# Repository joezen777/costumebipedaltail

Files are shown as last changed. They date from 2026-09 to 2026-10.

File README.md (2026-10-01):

# Passive suitmation tail: Barney-style, lumbar-belt mounted, ready to print

A completely passive (no motors, electronics or pneumatics) creature-suit tail for a **5 ft 8 in (1.727 m)**
performer. The client revision asked for:
- **half the length** of the earlier tail;
- a **Barney-like reverse-sigmoid curve**: starts up, goes down, then flattens so the end sticks straight back;
- a mount on a **pharmacy lower-lumbar support belt**;
- the **mechanics approved in the Gojira variant** kept.

It was validated in a MuJoCo physics model, then built as parametric OpenSCAD and FreeCAD models. The print-ready
parts are for an Ender 3 V2 / Sprite Pro with a **1.2 mm nozzle** (no part larger than a 20 cm cube), plus a
**1:8 snap-together resin kit** for the Photon Mono 5s, and a **1:8 low-poly figurine with a protogen head** whose
back slot takes the kit's plate at 14 heights.

- Design document: [docs/barney.md](docs/barney.md)
- Documentation index: [docs/README.md](docs/README.md)
- Original brief: [docs/brief.md](docs/brief.md)

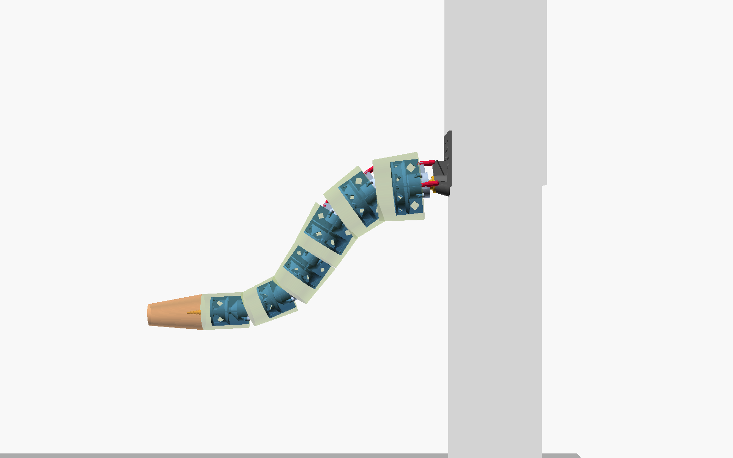
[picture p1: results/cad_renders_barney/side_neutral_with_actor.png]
Barney tail CAD assembly on the performer


---

## 1. The design

- **Length:** 0.90 m, a 6-joint × 125 mm ball-and-socket chain plus a 0.15 m rounded foam tip.
- **Proportions:** 190 mm thick at the root, 100 mm at vertebra 6, 60 mm at the tip.
- **Rest shape:** a reverse sigmoid, printed into wedge flanges on the balls. It leaves the back nearly level (6°),
  dips at up to 58° mid-tail, then the last vertebra and foam tip run level, sticking straight back.
- **Mount:** a plate strapped to the lumbar belt's back panel, with the tail root hanging 70 mm below it. One part
  covers both "attach directly" and "hang down".
- **Mechanics** (as approved):
  - dorsal + left + right extension springs per joint, anchored on cap ears (twist-stable);
  - felt seat liners;
  - a light central cord;
  - a roll-key screw per joint.

Simulated, with the masses measured from the exported parts:

| Test (as built) | Result |
|---|---|
| Rest (standing) | tail ends pointing back, skin **52 cm** above the floor |
| 30° hip snap | lag 34°, overshoot 10°, 1 swing-back, settles in 1.2 s |
| Jerk left (30° in 0.25 s) | lag 40°, overshoot 8° |
| 45° dramatic turn | overshoot 31° |
| Walking 1.5 / 2.0 steps/s | tip/hip 1.94 / 1.77 |
| Crouch (−150 mm, 10°) | min clearance 47 cm |
| Side step 300 mm | min clearance 50 cm |
| Bending over 45° | tail lifts; hip moment 7.0 N·m |
| Jump (25 cm) | no floor contact; hip moment 13.3 N·m |
| Peak moment on the lumbar belt (any test) | 13 N·m |

Levelling the end out (reverse sigmoid) also calmed the tail: walking sway dropped from ~2.4× to ~1.9× the hip,
and the snap overshoot from 17° to 10°. The end rides about half a metre off the floor.

Four changes made the short tail work, all found in simulation ([docs/barney.md](docs/barney.md)):
- **Reverse-sigmoid rest curve:** the first S-curve ended ~35° nose-down, like a hill, because it only flattened
  inside the foam tip, which can't bend. Now the last vertebra and tip are level and stick straight back.
- **Softer centring springs:** the tail first overshot the hips by 31°.
- **Round cap stop openings:** jump landings were hammering the pitch stops (23 → 7 N·m).
- **Bigger minimum ball (22 mm):** brings every neck to SF ≥ 3.5.

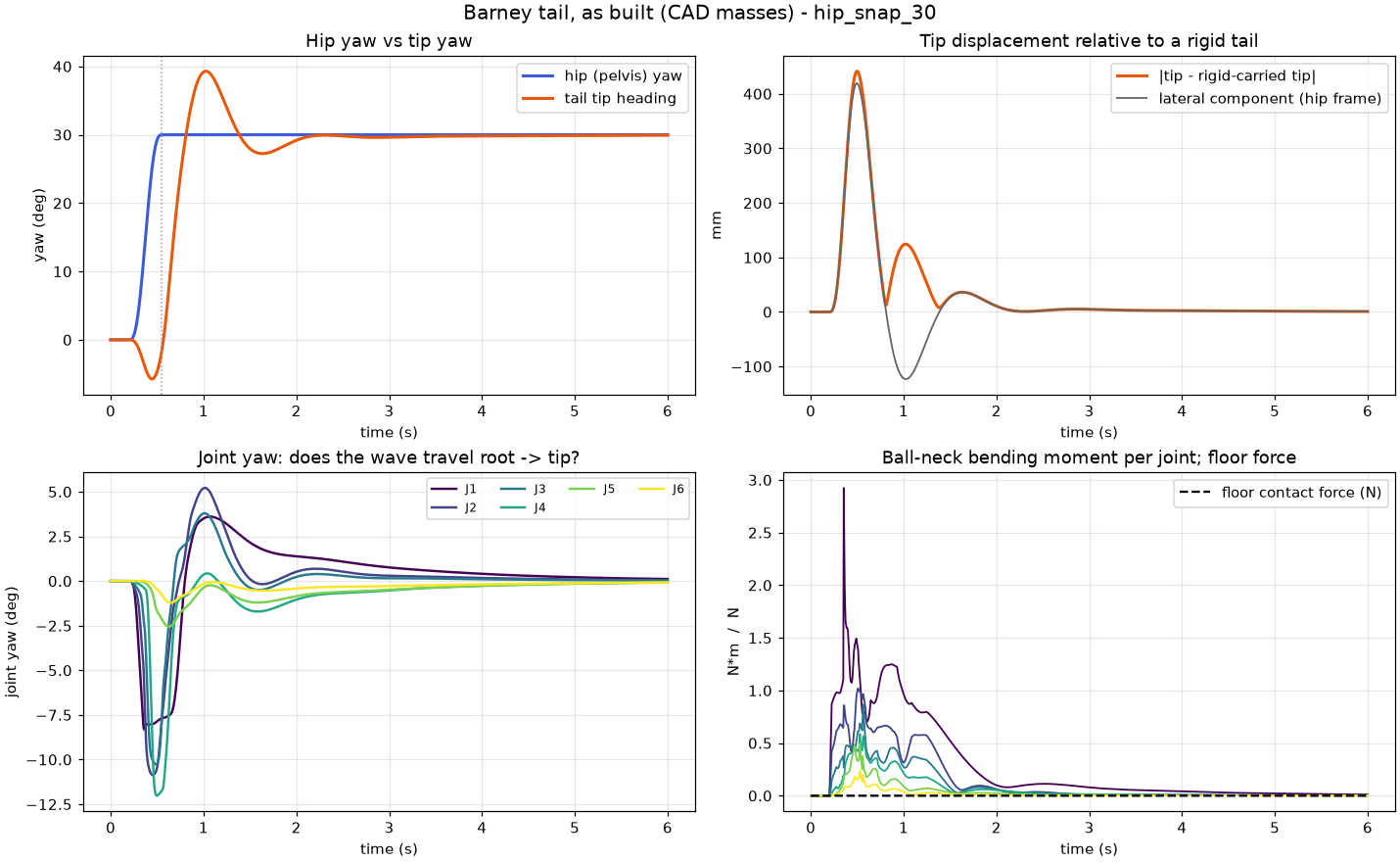
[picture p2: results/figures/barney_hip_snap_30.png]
Hip snap response


## 2. What to print (full size)

**[`cad/stl/barney/`](cad/stl/barney/): 32 print-ready STLs, 1.91 kg of PETG.**
- One hip mount, 6 vertebra bodies, 6 caps **printed as two halves each** (`cap_N_a` + `cap_N_b`), 12 ball halves
  (with the rest-curve wedges; keep them in joint order) and the tip adapter.
- **Caps are split on purpose.** A one-piece cap can't be fitted: its opening is smaller than both the ball and the
  ball's bolt flange. The two halves close around the neck of the assembled ball instead.
- Sizes and masses: [docs/tables/barney_parts.md](docs/tables/barney_parts.md).
- Settings: [docs/printing.md](docs/printing.md). PETG, 1.3 mm lines, 0.6 mm layers (0.4 mm for ball halves),
  100 % infill for ball halves 1–3.
- **No slicer supports:** the vertebra bodies and hip mount carry their own overhangs with thin structural walls
  (a 45° cone, an arched skirt, arm webs). Every part prints from `cad/stl/barney/` with slicer
  supports off; the few remaining roofs are short bridges. See [docs/printing.md](docs/printing.md).
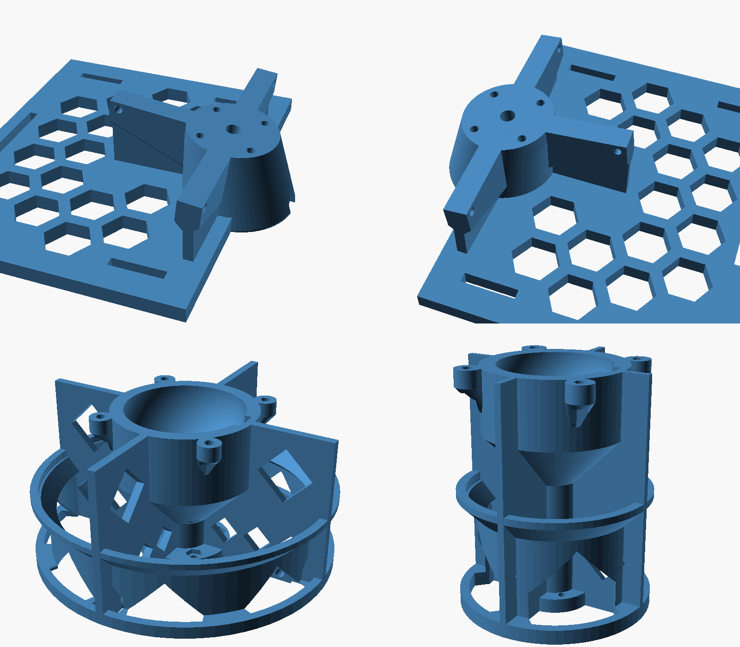
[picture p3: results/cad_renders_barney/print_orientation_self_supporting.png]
self-supporting parts
  
- The whole tail is only 6 joints, so it doubles as the prototype for the calibration tests in
  [docs/test_plan.md](docs/test_plan.md).

CAD: [`cad/openscad/suit_tail_barney.scad`](cad/openscad/suit_tail_barney.scad) (a generated variant of the
parametric [`suit_tail.scad`](cad/openscad/suit_tail.scad)); FreeCAD/STEP in [`cad/freecad/output/`](cad/freecad/output/).

### Shopping list (full-size tail)

Rough commodity prices in USD; buy about 10 % spare small hardware.

| Item | Qty | Use | ~Cost |
|---|---|---|---|
| PETG filament 1.75 mm | 3 × 1 kg | 1.91 kg of parts + purge and reprints (2 kg leaves under 0.1 kg spare) | $60 |
| 1.2 mm nozzle for the Sprite Pro | 1 | | $10 |
| M4 × 16 socket-head cap screws | 48 | 4 per cap + 4 per ball flange, 6 joints | $6 |
| M4 nylock nuts | 48 | press into the printed hex pockets | $4 |
| M4 × 12 socket-head (roll keys, all 6 joints) / M3 × 8 (tip adapter) | 6 / 4 | roll-key pins, tip adapter | $2 |
| **Extension springs** | **18** | 3 per joint; schedule in [docs/tables/barney_springs.md](docs/tables/barney_springs.md) | $20–35 |
| · heavy (dorsal J1–J2) | 2 | ~5.5–5.9 N/mm, 66–96 N at rest, up to ~145 N, OD ≤ 15 mm | |
| · medium (dorsal J3–J6) | 4 | ~1.6–3.3 N/mm, 9–41 N at rest, up to ~78 N, OD ≤ 12 mm | |
| · light (lateral pairs, all joints) | 12 | ~0.8–1.7 N/mm, 6–13 N at rest, up to ~33 N, OD 8–15 mm | |
| Compression spring Ø ≤ 13 mm, ~2 N/mm, ~20 mm long | 1 | cord preload at the tip | $2 |
| 6 mm braided polyester cord | 1.5 m | central cord | $4 |
| Cord lock + 2 washers | 1 set | tip end of the cord | $3 |
| Self-adhesive felt 0.5 mm; felt/rubber 0.8 mm | small sheets | seat liners; cap-mouth stop pads | $8 |
| **Lumbar support belt** (pharmacy lower-back brace, elastic with a rigid or semi-rigid back panel) | 1 | the mount | $20–35 |
| 25 mm hook-and-loop straps ~40 cm | 4 | through the plate's corner slots, around the belt's back panel | $8 |
| 50 mm webbing strap ~1 m + buckle (optional) | 1 | through the top slot for extra hold | $6 |
| EVA foam 3 mm | 200 × 160 mm | comfort pad behind the mounting plate | $3 |
| Upholstery foam (~20 mm and ~10 mm sheets) | ~1 m × 1 m | skin over the frame, 20 → 10 mm thick | $25 |
| Foam block | 150 × 100 × 100 mm | rounded 150 mm foam tip | $6 |
| 4-way stretch fabric + contact cement / spray adhesive | ~1 m² + 1 can | outer skin | $25 |
| 1.75 mm filament offcuts; CA or epoxy | 12 × 10 mm | ball-half dowels; glue | $5 |

Tools: 3.4 and 4.5 mm drill bits (to size printed holes), hex keys, 7 mm nut driver, pliers.
**Rough total ~$220–270 including the belt.**

### Springs delayed / no felt? Printed TPU 95A parts (0.4 mm nozzle)

[docs/tpu_bands.md](docs/tpu_bands.md) covers same-night stand-ins, all in TPU 95A with a 0.4 mm nozzle. No
other part changes.
- **Straps:** [`plate_all_straps.stl`](cad/stl/barney_tpu_bands/) holds all 24 straps for the 18 spring
  positions on one plate.
  - Each is labelled with joint and side (`3D`, `3L-T`), bolts through the existing spring holes with M4 bolts,
    and is fit-checked at every bend limit.
  - Preload is exact everywhere, and the rate matches on 15 of 18 positions (J1/J4/J5 dorsal are stiffer).
- **Felt substitutes:** [`cad/stl/barney_tpu_liners/`](cad/stl/barney_tpu_liners/).
  - **Seat liner webs** print flat and close into true meridians and latitude circles in the seat. In simulation
    they beat felt: settle 0.76 s against 1.25 s.
  - **Cap-mouth bumper rings** have a bore cut from the real neck swept to each stop, so TPU lands before PETG.
- **Washers:** 132 TPU M4 tension washers on one sheet.
- **Pre-existing finding:** the rest-bend wedges move the PETG stops. J5/J6 pitch-down has no cap stop until
  about 32–40°; see the doc.

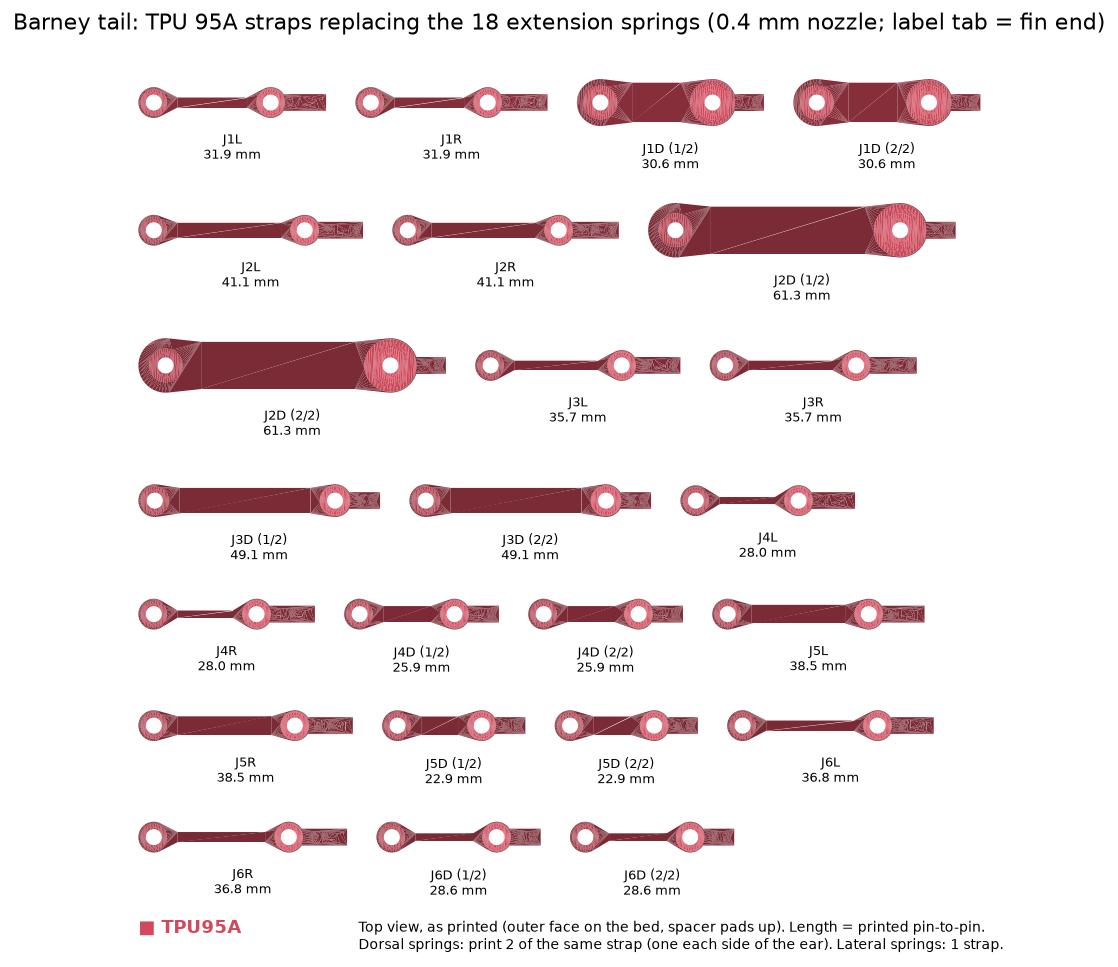
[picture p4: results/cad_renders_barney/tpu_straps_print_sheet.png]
TPU strap print sheet


### Assembly order (full size)

**In one line:** hip mount → ball 1 → body 1 → cap 1 halves → J1 springs → ball 2 → body 2 → cap 2 halves →
J2 springs → … → ball 6 → body 6 → cap 6 halves → J6 springs → tip adapter → cord → foam skin → belt.

**Caps come in two halves** (`cap_N_a` + `cap_N_b`). A one-piece cap can't be fitted at all: its opening is
smaller than both the ball and the ball's bolt flange.

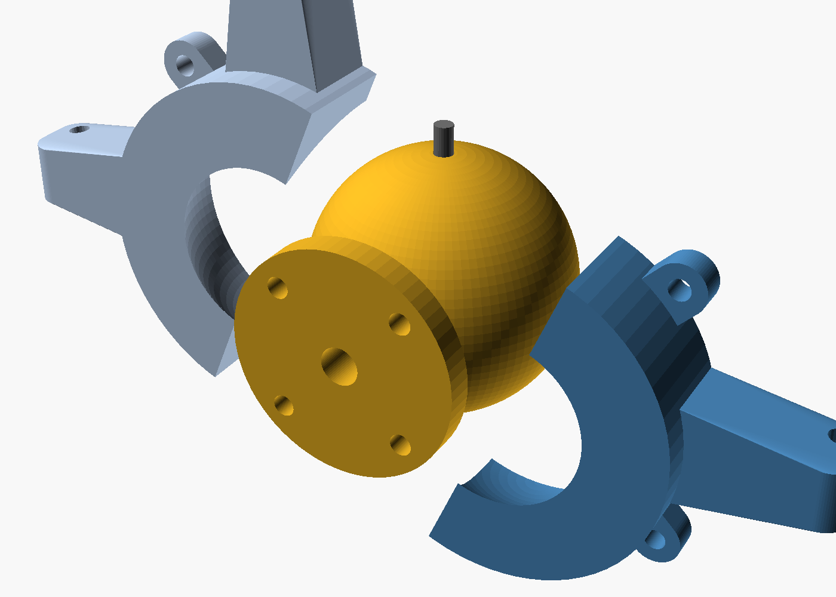
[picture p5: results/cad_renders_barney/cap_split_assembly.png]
cap halves closing around ball 1


1. **Prep:**
   - Drill the printed holes to size: 4.5 mm for M4, 3.4 mm for M3.
   - Press M4 nylock nuts into every hex pocket: 4 in the hip mount, 8 in each of bodies 1–5 (4 at the socket
     end for the cap, 4 at the distal flange for the next ball), and 4 in body 6 (socket end only).
2. **Hip mount:** start here, and lay it plate-down on the bench.
3. **Ball 1:**
   - Put the roll-key screw in one half of ball 1 (M4 × 12, head in the pocket, shank out of the dorsal hole).
   - Close the second half onto two 1.75 mm filament dowels, and glue if you want.
4. **Ball 1 → hip mount:** bolt ball 1's flange to the hip mount's flange with 4 × M4 × 16. The bolt heads go on
   the neck side.
5. **Body 1:**
   - Line its socket seat with felt or PTFE tape.
   - Set it onto ball 1 with the roll-key screw in the seat's dorsal slot.
6. **Cap 1 → body 1:**
   - Close the two cap-1 halves around ball 1's neck **about 5 mm back from the body**, toward the flange. The
     spherical side faces the ball.
   - Half `b` (the one with the dorsal ear and the key slot) goes on the roll-key side.
   - Hold them together, then slide the closed cap forward onto body 1. The roll-key screw slides into the cap's
     key slot from its open end.
   - Bolt it with 4 × M4 × 16 (2 per half). Ball 1 is now captured; check that the joint swivels.
   - Don't try to push a half straight into its final spot: half `b` would hit the roll-key screw.
7. **J1 springs:**
   - Hook the three springs from the hip-mount arms to cap 1's ears: dorsal (the heavy, strongly preloaded one),
     left and right.
   - The rates are in [docs/tables/barney_springs.md](docs/tables/barney_springs.md).
8. **Joints 2–6:** repeat steps 3–7, with each new ball bolting to the *previous body's distal flange*:

   | Joint | Ball bolts to | Body | Cap halves | Springs run from → to |
   |---|---|---|---|---|
   | J2 | body 1 distal flange | body 2 | cap_2_a + cap_2_b | body 1 fin holes → cap 2 ears |
   | J3 | body 2 distal flange | body 3 | cap_3_a + cap_3_b | body 2 fin holes → cap 3 ears |
   | J4 | body 3 distal flange | body 4 | cap_4_a + cap_4_b | body 3 fin holes → cap 4 ears |
   | J5 | body 4 distal flange | body 5 | cap_5_a + cap_5_b | body 4 fin holes → cap 5 ears |
   | J6 | body 5 distal flange | body 6 | cap_6_a + cap_6_b | body 5 fin holes → cap 6 ears |

   Ball halves are **not interchangeable** between joints, because each carries its joint's rest-bend wedge. Keep
   them numbered.
9. **Tip adapter → body 6:** screw it to body 6's distal flange with 4 × M3 × 8.
10. **Cord:**
    - Thread the 6 mm cord from the tip adapter through every bore and out of the hip mount's belt-side face.
    - Tie a figure-eight or double-overhand stopper knot, pull it up into the knot chamber, and tuck the loose end
      down the rope tunnel.
    - At the tip, add washer + compression spring + washer + cord lock. Compress the spring about 5 mm (10 N
      preload).
11. **Foam:**
    - Glue the foam skin to the rings and fin edges (20 mm at the root, 10 mm at the tip).
    - Glue the foam tip over the tip-adapter spike, and cover everything with the stretch fabric.
12. **Belt:**
    - Put the 3 mm EVA pad on the plate's belt side.
    - Strap the plate to the lumbar belt's back panel through the four corner slots, plus the optional top webbing
      strap.

The detailed notes (liners, spring preload, printing) are in [docs/printing.md](docs/printing.md#assembly).

## 3. 1:8 snap-together resin kit (Photon Mono 5s)

**[`cad/stl/replica_1to8_resin/`](cad/stl/replica_1to8_resin/)**: a working miniature of the mechanism, about 11 cm
long.
- **Joints:** each vertebra **clicks** into the next with a slotted snap-fit ball and socket.
- **Cord:** **twine** (0.8–1 mm) threads through the centre, like the cord.
- **Springs:** **orthodontic elastics** (1/8" medium) hook over mushroom pegs, 4 per joint (24 total).
- **Rest curve:** the reverse-sigmoid curve is built into the necks.
- **Also included:** the lumbar-belt plate with a tab, a display stand, and a snap test coupon to print first.

Print settings, assembly and the kit shopping list are in that folder's
[README](cad/stl/replica_1to8_resin/README.md).

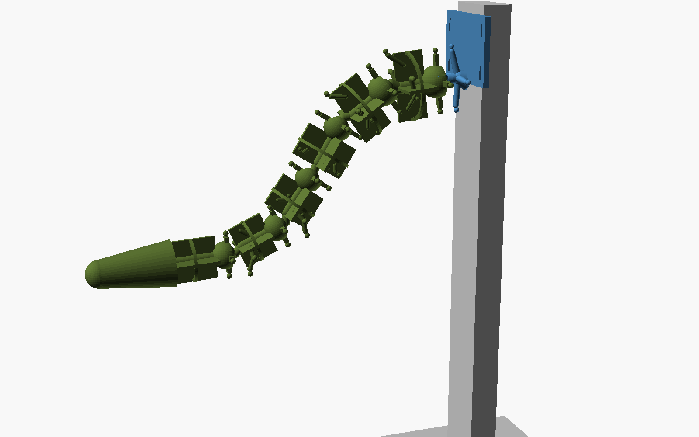
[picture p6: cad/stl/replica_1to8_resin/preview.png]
1:8 kit assembled


### 1:8 figurine with a protogen head

**[`cad/stl/figurine_1to8_resin/`](cad/stl/figurine_1to8_resin/)**: a low-poly 5 ft 8 in male at 1:8 with a
protogen head, for trying the kit at different heights.
- **Back slot:** a T-slot rail on the back takes the kit's hip plate unchanged. It slides in from the top.
- **Levels:** pins through the lip holes stop the plate at 14 levels, from 128 mm below to 288 mm above the design
  height (full-size).
- **Parts:** body, head, base and two level pins.

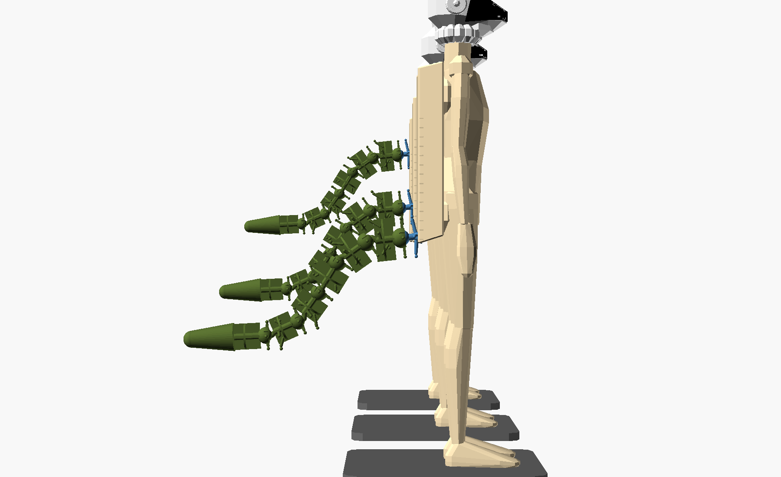
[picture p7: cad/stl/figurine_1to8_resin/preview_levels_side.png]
figurine with the tail at three levels


## 4. The tail on a performer: five simulated poses

Every row is one instant of the as-built simulation, shown three ways:
1. **Photo:** a Z-Image Turbo image-to-image pass over the physics render, which keeps the simulated geometry.
2. **Physics render.**
3. **CAD render:** the real exported parts articulated with the simulated joint angles.

| Pose | Simulated photo | Physics render | CAD render |
|---|---|---|---|
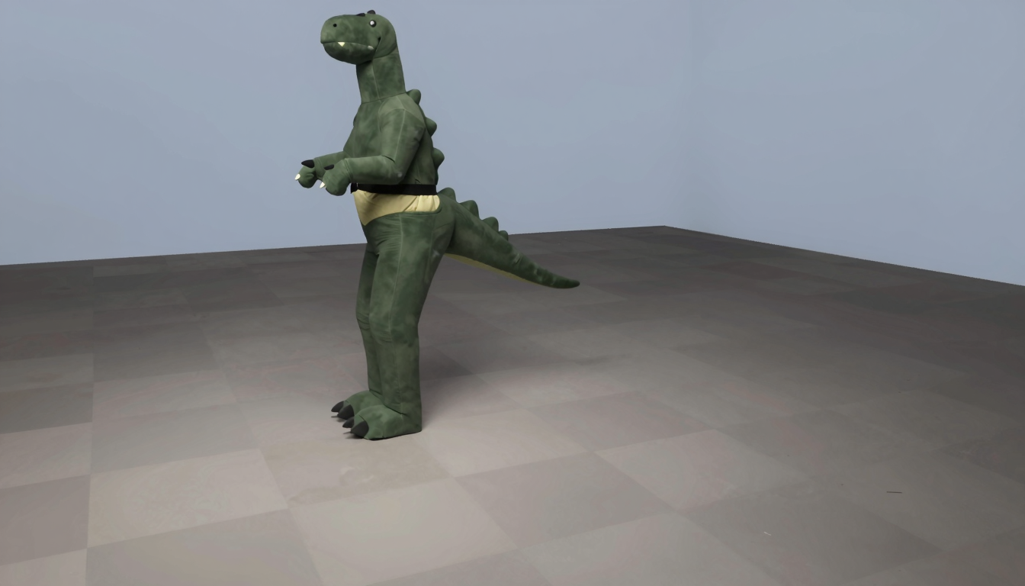
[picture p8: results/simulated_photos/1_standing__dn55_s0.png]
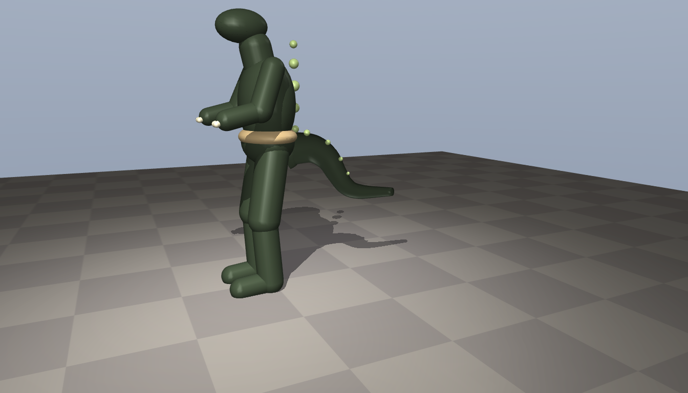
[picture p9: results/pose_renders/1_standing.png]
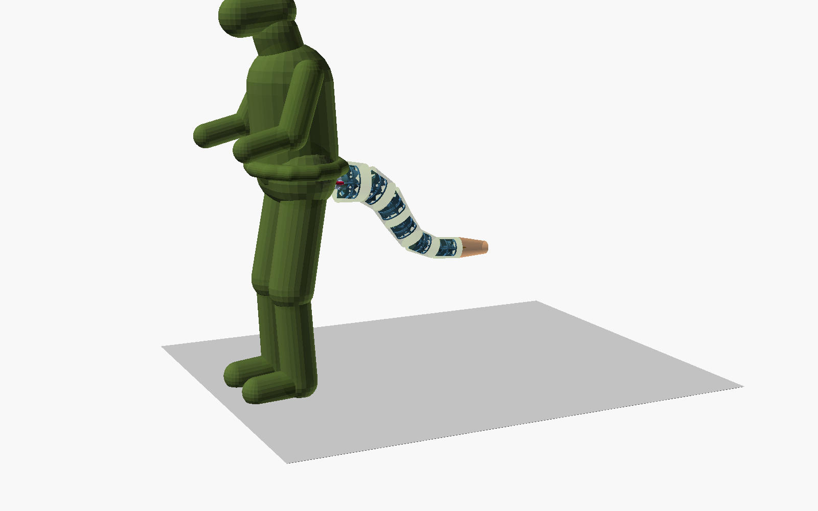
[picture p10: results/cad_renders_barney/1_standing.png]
| Standing still |  |  |  |
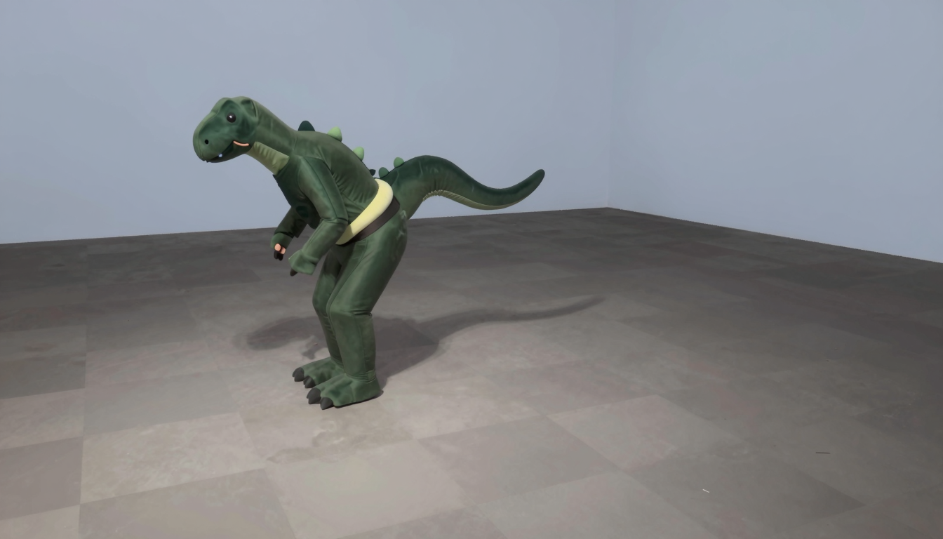
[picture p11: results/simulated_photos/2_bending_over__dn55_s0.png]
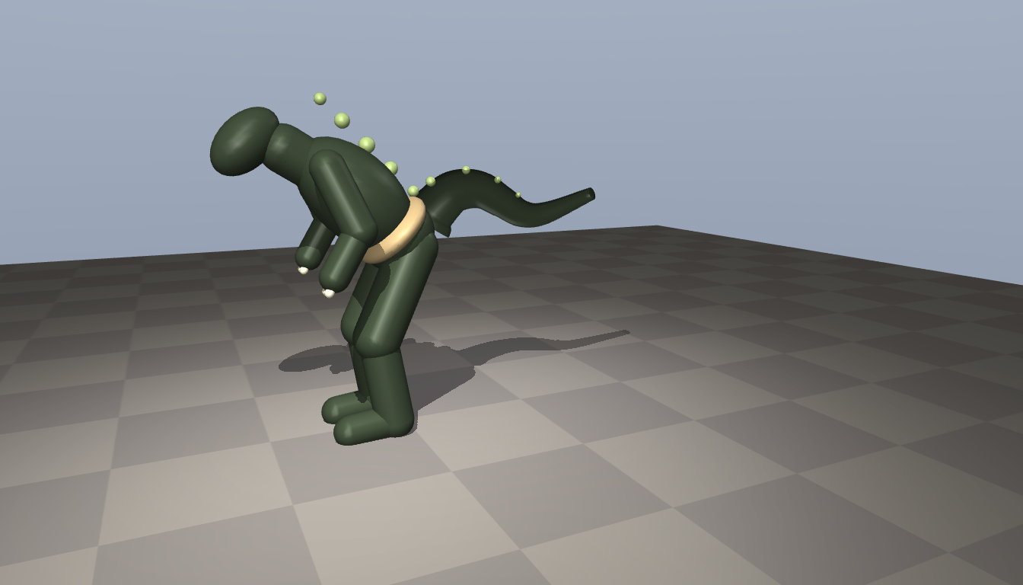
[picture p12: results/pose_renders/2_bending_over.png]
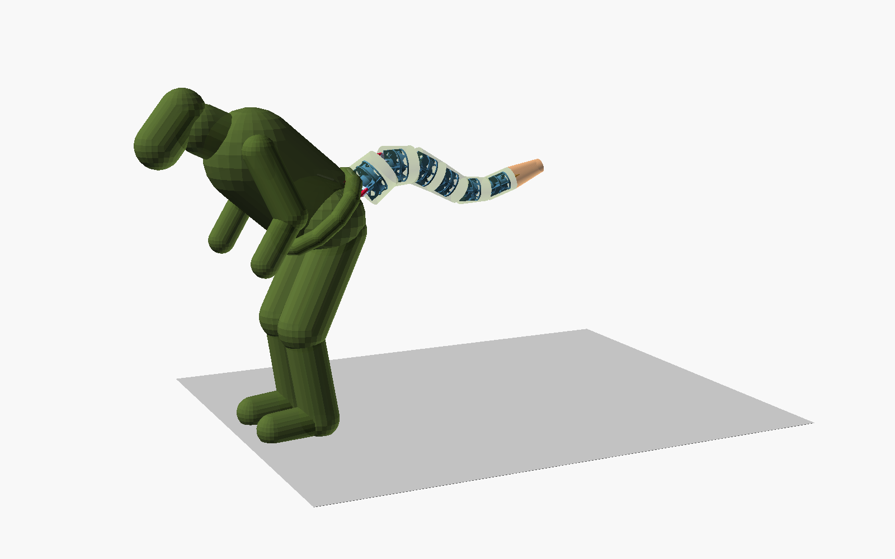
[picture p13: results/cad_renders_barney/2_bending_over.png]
| Bending over |  |  |  |
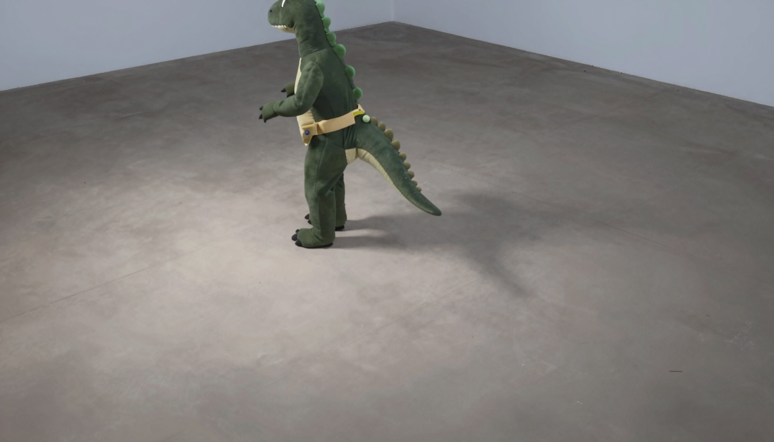
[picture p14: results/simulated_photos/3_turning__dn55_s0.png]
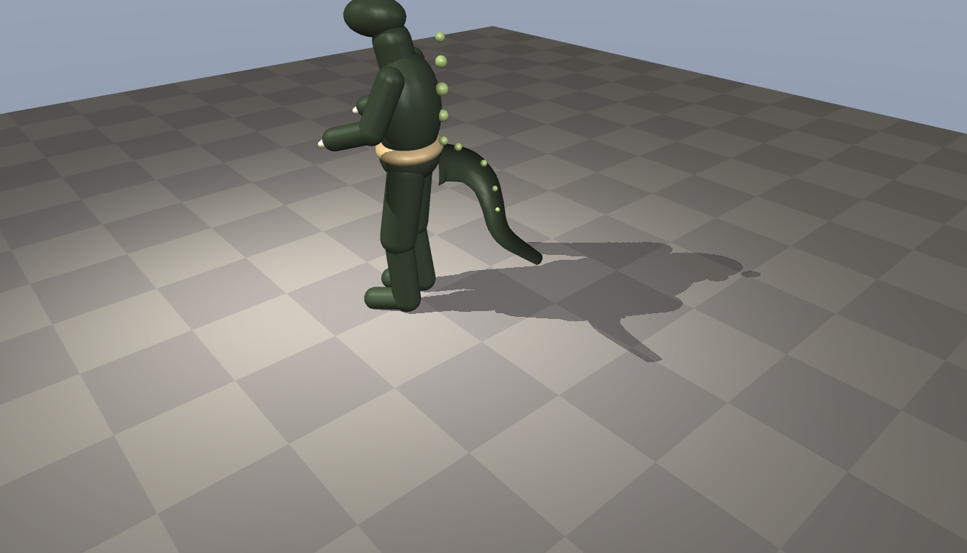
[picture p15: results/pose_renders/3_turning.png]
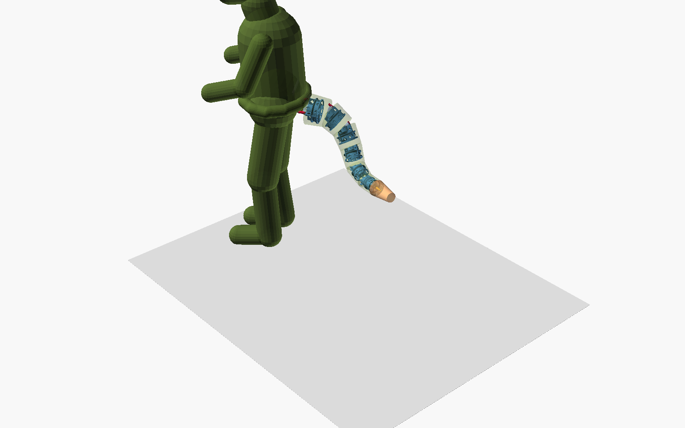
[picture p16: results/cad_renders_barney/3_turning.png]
| Turning (45°) |  |  |  |
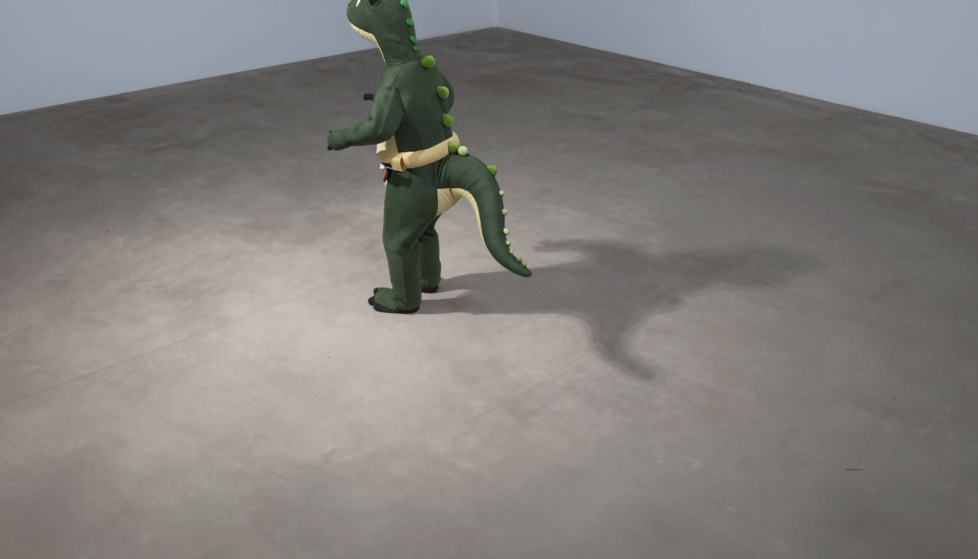
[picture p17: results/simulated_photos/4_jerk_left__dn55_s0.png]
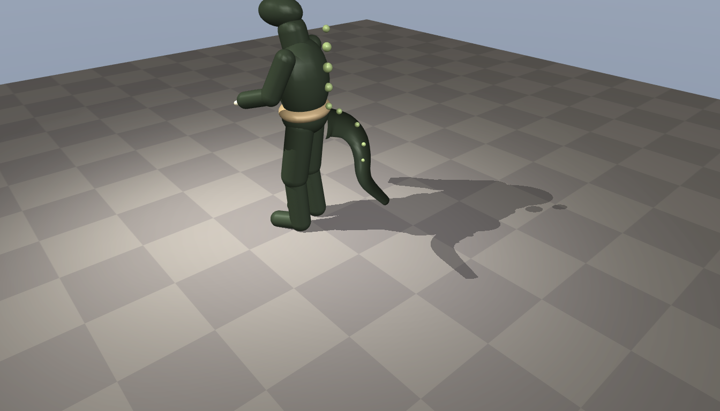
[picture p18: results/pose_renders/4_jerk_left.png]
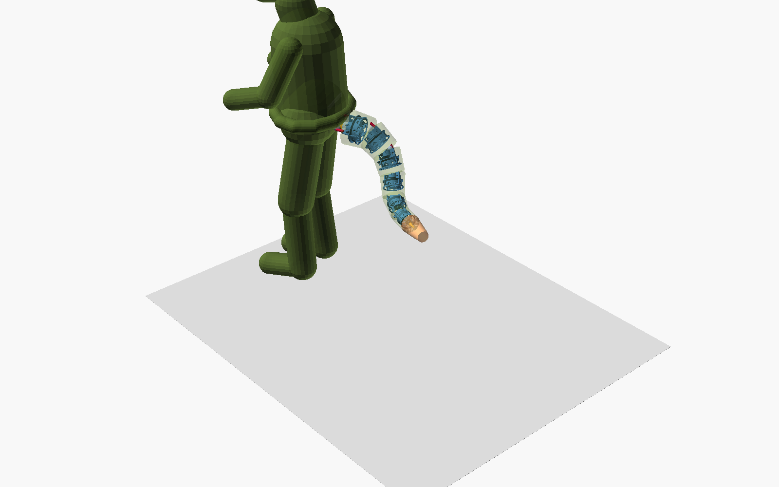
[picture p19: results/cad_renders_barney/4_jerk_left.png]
| Jerk to the left |  |  |  |
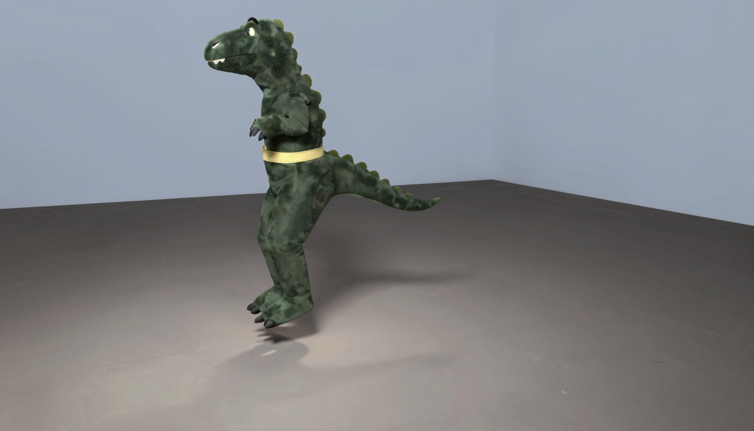
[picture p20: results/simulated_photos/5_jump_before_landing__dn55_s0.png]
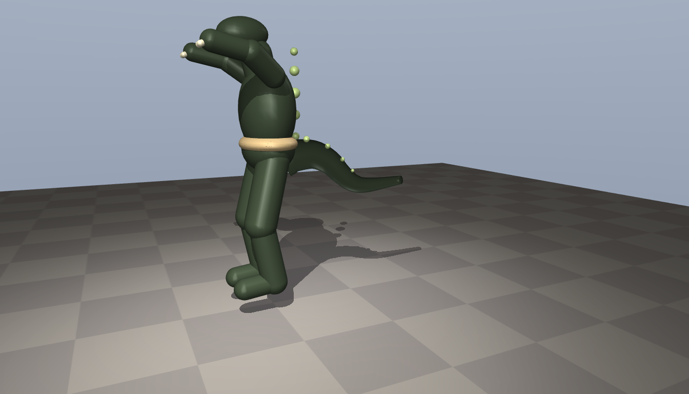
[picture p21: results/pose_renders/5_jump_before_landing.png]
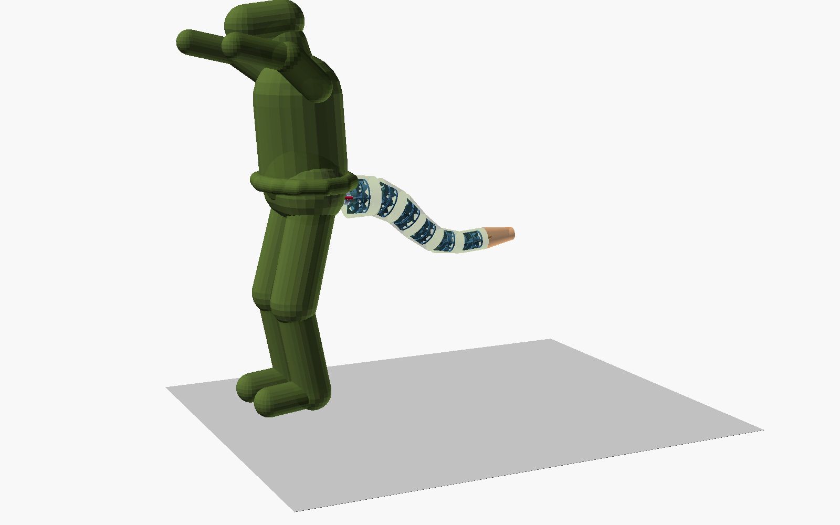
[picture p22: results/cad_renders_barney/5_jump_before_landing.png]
| Jump, just before landing |  |  |  |

More CAD views in [`results/cad_renders_barney/`](results/cad_renders_barney/):
- top, moderate turn, maximum curvature with limit cones;
- cord path, exploded vertebra, joint sections, hip mount.

| Maximum curvature (limit cones) | Exploded vertebra | Hip mount / belt plate |
|---|---|---|
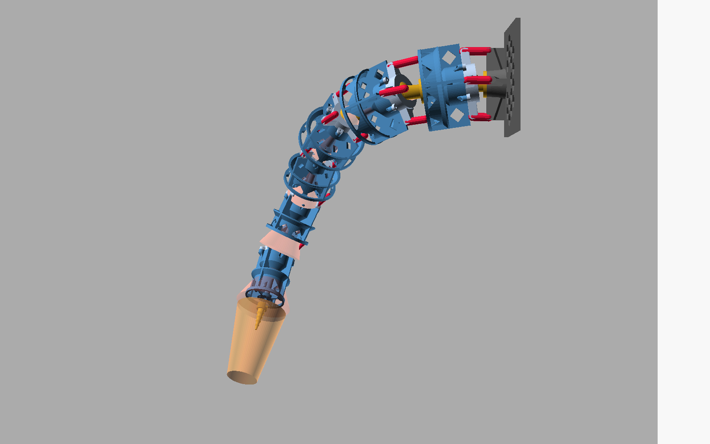
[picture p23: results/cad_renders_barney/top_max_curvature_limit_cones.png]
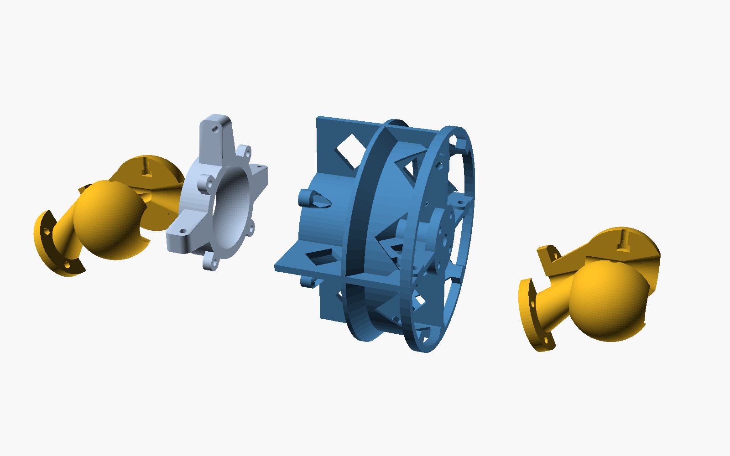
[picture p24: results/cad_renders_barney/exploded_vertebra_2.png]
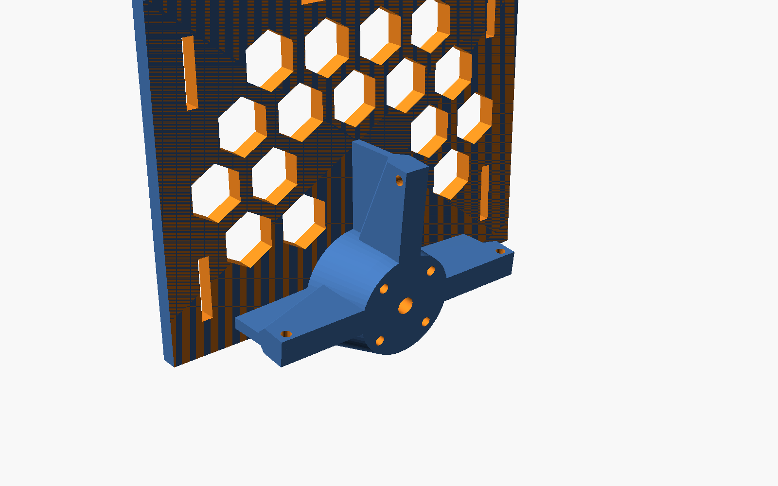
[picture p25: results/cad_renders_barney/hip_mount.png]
|  |  |  |

## 5. How the mechanism was established (design history)

The approved mechanics came from a physics study of the brief's original 1.4 m tail, followed by a 1.8 m
"Gojira" hover variant. Both variants' CAD, exports and renders were replaced by this revision; the findings and
plots remain.

| Finding | Evidence |
|---|---|
| Friction and stops alone can't swing back: **centring springs are required** | [naive vs spring spine](results/figures/study_naive_hip_snap.png), [animation](results/animations/naive_vs_reference_hip_snap.gif) |
| A preloaded spring anchored distal of the pivot causes a **twist instability**; anchoring the child end on the cap proximal of the pivot fixes it | [docs/physics.md §2.4](docs/physics.md), [docs/design.md](docs/design.md) |
| Springs must beat the friction dead band; the **seat liner is the main tuning knob**, cord preload hardly matters | [liner](results/figures/hardware_friction_hip_snap.png), [preload](results/figures/hardware_preload_hip_snap.png) |
| The **roll key** keeps swing energy from leaking into twist | [roll study](results/figures/hardware_com_roll_hip_snap.png), [animation](results/animations/roll_free_vs_roll_key.gif) |
| Configurations A–D on identical inputs | [comparison](results/figures/compare_ABCD_hip_snap_30.png), [docs/tables/study.md](docs/tables/study.md) |
| Rigid gate hinges are unsafe near the floor (860 N on a jump landing); an elastic tube can't hold a shape and swing | [docs/gojira.md](docs/gojira.md) |

Validation ([tests/test_physics.py](tests/test_physics.py), [tests/test_cad.py](tests/test_cad.py), all passing):
- **Physics:** statics; ball loads against hand calculations; energy conserved except for the stop constraints; the
  linear modes match the time-domain simulation; dt convergence; hip tracking; tension-only springs; the
  gravity-bias torque.
- **CAD:** OpenSCAD matches the Python spec (default and Barney variants); every Barney part is one watertight volume
  that fits the printer.

## Reproduce

```bash
python3 -m venv ~/.venvs/costumebipedaltail && ~/.venvs/costumebipedaltail/bin/pip install -r requirements.txt
PYTHONPATH=. ~/.venvs/costumebipedaltail/bin/python -m unittest -v tests.test_physics tests.test_cad
PYTHONPATH=. ~/.venvs/costumebipedaltail/bin/python cad/make_variant.py barney           # CAD variant from the design
cd cad && ~/.venvs/costumebipedaltail/bin/python export_stl.py --variant barney --no-kit && cd ..
PYTHONPATH=. ~/.venvs/costumebipedaltail/bin/python experiments/barney.py                # design + as-built simulation
PYTHONPATH=. ~/.venvs/costumebipedaltail/bin/python experiments/barney_tables.py         # springs / strength / mass tables
PYTHONPATH=. ~/.venvs/costumebipedaltail/bin/python cad/export_replica.py                # 1:8 resin kit
PYTHONPATH=. ~/.venvs/costumebipedaltail/bin/python cad/export_figurine.py               # 1:8 protogen figurine
TAIL_VARIANT=barney ~/Applications/freecad-experiment/squashfs-root/usr/bin/freecadcmd cad/freecad/build_tail.py
python3 cad/render_views.py --variant barney                                             # CAD views
MUJOCO_GL=egl PYTHONPATH=. ~/.venvs/costumebipedaltail/bin/python experiments/pose_renders.py
PYTHONPATH=. ~/.venvs/costumebipedaltail/bin/python experiments/cad_pose_renders.py
python3 experiments/photoreal.py                                                         # needs ComfyUI (~/comfyuiinstall.sh)
```

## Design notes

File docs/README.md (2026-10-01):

# Passive suitmation tail: documentation index

Brief: [brief.md](brief.md) (original design brief). Results overview: [../README.md](../README.md). Environment rules: `../AGENTS.md`.

| Document | Contents |
|---|---|
| [barney.md](barney.md) | **Current design:** Barney-style 0.9 m tail on a lumbar belt: design, simulated behaviour, build files |
| [gojira.md](gojira.md) | (Superseded variant) Gojira "x² + 1" hovering profile: five mechanisms compared; the approved mechanics came from here |
| [physics.md](physics.md) | Simulation model, the design findings it produced, validation tests, how to reproduce |
| [design.md](design.md) | Mechanical architecture, twist-stable spring geometry, performer fit (5 ft 8 in), strength approach |
| [printing.md](printing.md) | 1.2 mm nozzle settings, print orientation per part, material choice (PETG vs PLA/TPU vs resin), hardware list, assembly |
| [tpu_bands.md](tpu_bands.md) | **TPU 95A stand-ins (0.4 mm nozzle):** labelled spring straps on one plate, seat liner webs and cap-mouth bumper rings instead of felt, M4 tension washers, coupon calibration, install, the measured stop-angle finding ([tables/tpu_bands.md](tables/tpu_bands.md), [tables/tpu_band_sim.md](tables/tpu_band_sim.md)) |
| [test_plan.md](test_plan.md) | 4-joint physical prototype: build, ballast, measurements that calibrate the model |
| [tables/barney_parts.md](tables/barney_parts.md) | **Print list** (what to print), sizes and masses |
| [tables/barney_springs.md](tables/barney_springs.md) / [barney_strength.md](tables/barney_strength.md) / [barney_mass_budget.md](tables/barney_mass_budget.md) | Barney tail springs, strength and mass |
| [tables/study.md](tables/study.md) | Every configuration on identical hip inputs (README §27 A–D plus ablations) |
| [tables/hardware.md](tables/hardware.md) | The *same built tail* with cord preload, friction liner, COM and roll key changed |
| [tables/springs.md](tables/springs.md) | Spring schedule: rate, preload, installed length per joint |
| [tables/strength.md](tables/strength.md) | Peak simulated loads vs printed-section capacity |
| [tables/mass_budget.md](tables/mass_budget.md) | Moving mass per segment from the exported CAD vs the README targets |

## Where the files are

| Path | What |
|---|---|
| `tailsim/` | MuJoCo physics package (parameters, model builder, simulator, metrics, plots, linear modes, mass budget) |
| `tests/` | `test_physics.py` (8 physics validation tests), `test_cad.py` (OpenSCAD ⇄ Python spec, printability) |
| `experiments/` | `sweep.py` (tuning), `run_suite.py` (study + media), `make_tables.py` (docs tables) |
| `cad/geometry.py` | Single dimensional spec shared by physics, OpenSCAD test and FreeCAD |
| `cad/openscad/suit_tail.scad` | Parametric OpenSCAD model (README §20 modules and PART views, plus print-oriented parts) |
| `cad/freecad/build_tail.py` | Parametric FreeCAD model (`createVertebra(index, parameters)`), writes FCStd + STEP |
| `cad/freecad/output/` | `suit_tail_barney.FCStd/.step` |
| `cad/openscad/suit_tail_barney.scad`, `cad/variants/barney.json` | Barney variant parameters (generated by `cad/make_variant.py` from the simulated design) |
| `cad/stl/barney/` | **Print-ready STLs for the Barney tail** (6 joints); `cad/stl/parts_barney.json` = sizes, volumes, masses |
| `cad/tpu_bands.py`, `cad/check_tpu_bands.py`, `cad/stl/barney_tpu_bands/` | TPU strap generator (spring targets → strap sections and lengths, nozzle profiles, labels, plates, coupon calibration), fit check against the part meshes, strap STLs |
| `cad/tpu_liners.py`, `cad/check_tpu_liners.py`, `cad/stl/barney_tpu_liners/` | Seat liner webs (flat → sphere gore mapping), cap-mouth bumper rings (bore from the swept neck), TPU M4 washer sheet; stop-angle mesh check |
| `cad/add_support_columns.py` | Overhang checker (optionally writes break-away columns). The bodies and hip mount are self-supporting by design |
| `cad/stl/replica_1to8_resin/`, `cad/openscad/mini_kit.scad` | 1:8 snap-together resin kit (twine + orthodontic elastics); `cad/export_replica.py` |
| `cad/stl/figurine_1to8_resin/`, `cad/openscad/figurine_1to8.scad` | 1:8 low-poly protogen-head figurine with a T-slot for the kit's plate at 14 levels; `cad/export_figurine.py`, `cad/render_figurine.py` |
| `results/figures/`, `results/animations/`, `results/cad_renders_barney/`, `results/pose_renders/`, `results/simulated_photos/` | Plots, animations, CAD views, pose renders, photos |
| `results/data/` | Metrics JSON, per-timestep CSVs (`csv/`), mass budget |

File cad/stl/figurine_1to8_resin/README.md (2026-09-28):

# 1:8 low-poly display figurine with a protogen head

A 1:8 stand-in for the performer, for trying the [1:8 resin tail kit](../replica_1to8_resin/README.md) at
different heights on the back. It's printed on the Anycubic Photon Mono 5s in ABS-Like Pro 2.
- **Body:** a skinny 5 ft 8 in (1727 mm) male at 1:8, so 216 mm to the crown of a human head. Key heights follow
  standard anthropometric fractions of stature (shoulder 0.82 H, hip joint 0.53 H, knee 0.285 H). The pelvis centre
  sits 0.55 H above the floor, which is the same frame the tail CAD uses.
- **Head:** a protogen head replaces the human one:
  - a black visor with recessed pixel eyes and a zigzag mouth;
  - tall ears with inner-ear recesses;
  - round side "ear" discs with an LED ring groove;
  - a fur ruff at the neck.

  It sits on a Ø3.9 mm neck peg, so it can turn.
- **Style:** deliberately low-poly (8-facet organic shapes), which keeps the files small and the export light.
  The mechanical fits (peg, socket, pin holes, the channel) keep full resolution.

three plate levels

## The back slot

A raised "cyber spine" rail on the back carries a T-channel that takes the kit's `01_hip_mount_plate` unchanged:
- **Edges:** the plate's edges run behind two lips, with 0.2 mm clearance.
- **Tab:** its stand tab runs in a centre groove.
- **Front face:** it sits exactly where the full-size design puts it (120 mm behind the pelvis centre at 1:1).
- **Insertion:** slide the plate in from the top of the rail.
- **Level pins:** push a level pin (`23_level_pin`, or a 1 mm paperclip wire) through a pair of lip holes, and
  the plate's bottom edge rests on the pins.

| Pin row | Plate raised from the design height (1:8 / full size) |
|---|---|
| none (plate on the channel floor) | −16 mm / −128 mm (lowest) |
| 13 rows, 4 mm apart | −12 … +36 mm / −96 … +288 mm |
| long tick mark | 0 = the approved design height |

The boss and joint-1 ball under the plate pass out through an opening in the bottom of the rail.
`export_figurine.py` slides the real plate STL through every level and checks it doesn't touch the body
(`plate_clearance` in `report.json`: all zero).

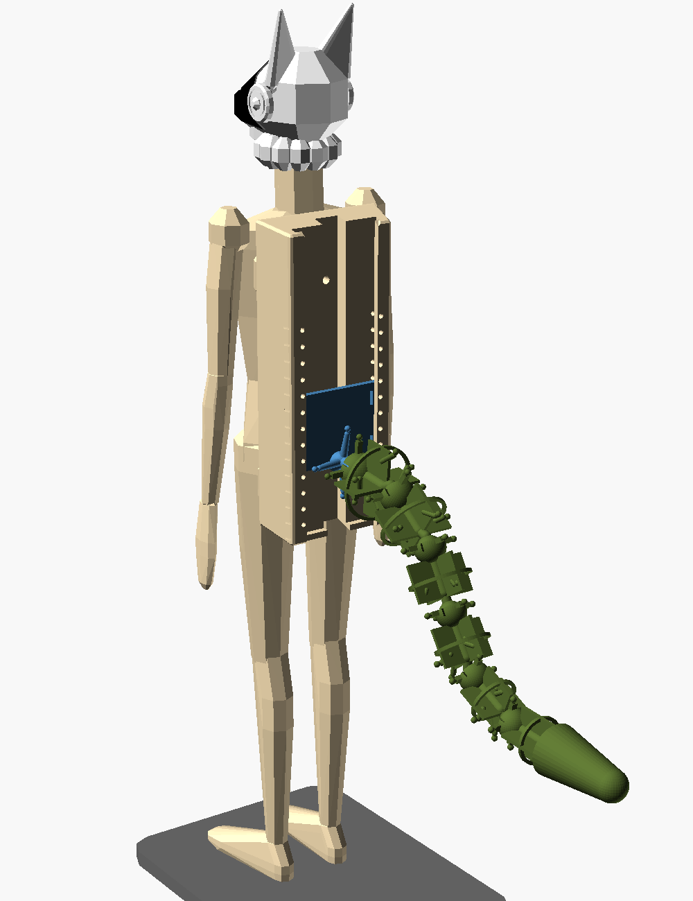
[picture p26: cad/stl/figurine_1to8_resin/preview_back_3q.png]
back view
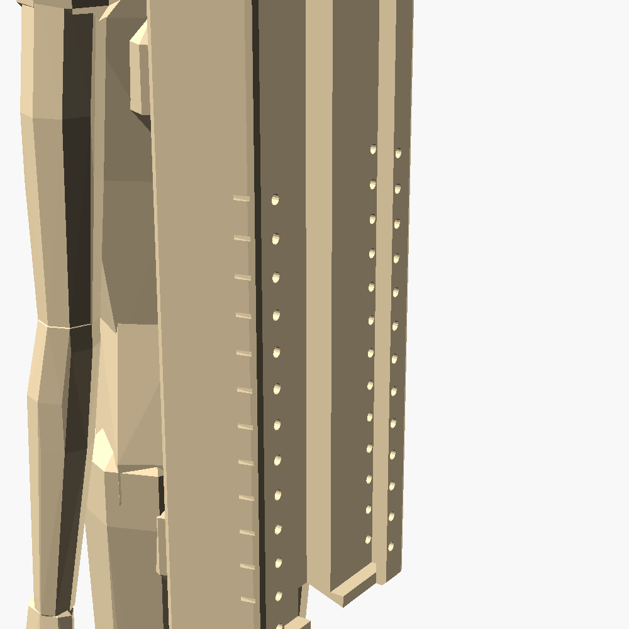
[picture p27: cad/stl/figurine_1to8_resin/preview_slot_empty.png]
empty slot
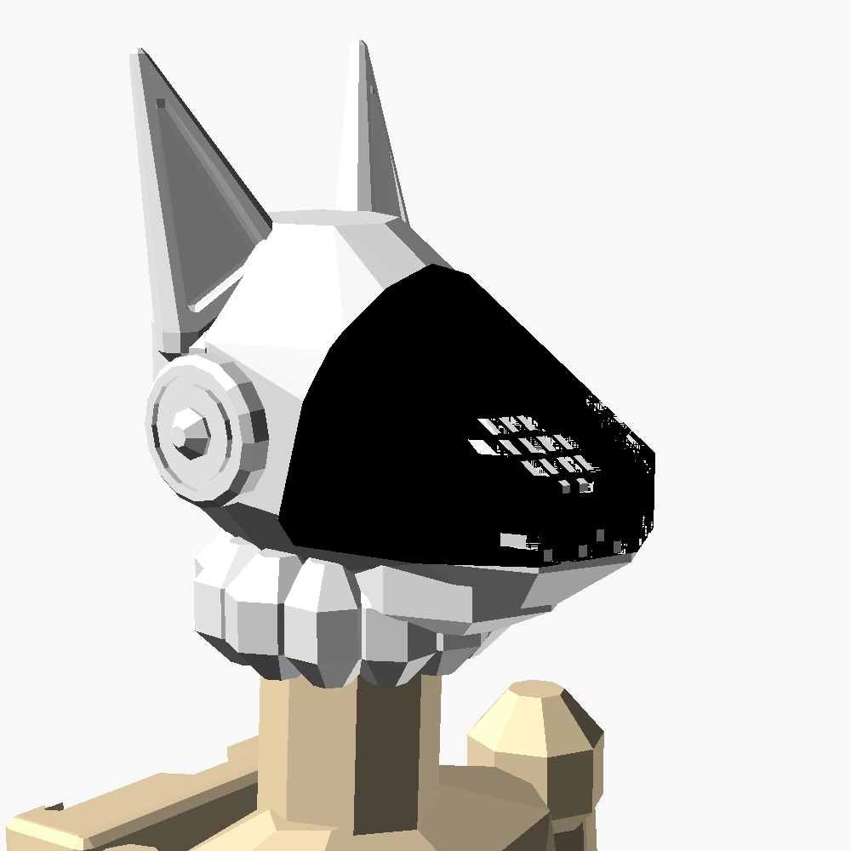
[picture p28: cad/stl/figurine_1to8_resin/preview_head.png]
protogen head
  

## Print list

| File | Size (mm) | Resin (ml) | Notes |
|---|---|---|---|
| `20_figure_body.stl` | 44.5 × 55.9 × 194.7 | 56.7 | torso hollowed (2 mm wall) |
| `21_protogen_head.stl` | 35.2 × 26.9 × 37.9 | 9.8 | |
| `22_display_base.stl` | 86 × 64 × 4 | 21.8 | fine on the Ender 3 V2 in PETG too |
| `23_level_pin.stl` | 2.2 × 2.2 × 7.2 | <0.01 | print 2 (plus spares) |

- **Body:**
  - At 195 mm, the body fits the 200 mm Z height upright. Keep any tilt in the slicer under about 10°, or lay
    it at about 45°, which fits the 218 mm X axis.
  - Put supports on the soles, the underside of the hands, and the chin of the neck. Keep them out of the
    channel.
  - The torso is hollow. Resin drains through a Ø2.4 mm hole in the crotch and vents into the top of the tab
    groove. Flush both holes well before curing.
- **Head:** print it upright on its ruff, lightly supported under the snout and ruff, with no supports in the
  peg socket.
- **Layers:** 0.05 mm. Wash and cure gently.

## Assembly

1. Push the head onto the neck peg.
2. Press the foot pegs into the base and glue them if you like.
3. Assemble the tail kit on its hip plate as its README describes, then slide the plate into the rail from the
   top.
4. Push a pin through both holes of the chosen row. Slide the plate down onto it.

The figure, head, base, plate and tail total about 103 g of resin. The combined centre of mass is 43 mm ahead of
the base's rear edge, so it won't tip at any level.

## Regenerate

```
PYTHONPATH=. ~/.venvs/costumebipedaltail/bin/python cad/export_figurine.py   # STLs + checks (~2 min, ~2.5 GB RAM)
PYTHONPATH=. ~/.venvs/costumebipedaltail/bin/python cad/render_figurine.py   # preview images
```
The source is `cad/openscad/figurine_1to8.scad`. Use `LP` for facet count, `LEVELS`/`DZ_MIN` for the pin rows,
and `c_x`, `c_y` for the channel clearances.

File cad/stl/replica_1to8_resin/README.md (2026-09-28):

# 1:8 scale snap-together resin replica: Barney tail

A working miniature of the approved mechanism, printed on the Anycubic Photon Mono 5s in ABS-Like Pro 2. It's scaled
1:8 from the full-size Barney tail (0.9 m becomes ~11 cm):
- **Joints:** each vertebra **clicks** into the next with a ball-and-socket snap joint. The socket cup has three
  flex slits.
- **Cord:** twine threads through the centre bore, standing in for the braided cord.
- **Springs:** orthodontic (dental brace) elastics hook over mushroom pegs.
- **Rest curve:** the reverse-sigmoid rest curve is built into the kinked necks, as the full-size wedge flanges build it in.

assembled preview

## Print list (one of each)

| File | Size (mm) | Resin (ml) |
|---|---|---|
| `00_snap_test_coupon.stl` | 23.7x20.0x8.9 | 0.5 |
| `01_hip_mount_plate.stl` | 15.9x23.8x27.0 | 1.137 |
| `99_display_stand.stl` | 147.5x36.0x135.7 | 30.114 |
| `11_vertebra_1.stl` | 20.3x18.8x20.4 | 0.585 |
| `12_vertebra_2.stl` | 19.7x17.1x18.4 | 0.504 |
| `13_vertebra_3.stl` | 18.9x15.7x15.7 | 0.438 |
| `14_vertebra_4.stl` | 19.6x14.3x16.5 | 0.417 |
| `15_vertebra_5.stl` | 19.4x13.9x15.5 | 0.38 |
| `16_vertebra_6.stl` | 37.9x13.3x13.3 | 1.927 |

- `00_snap_test_coupon`: a socket and ball for the largest and smallest joint. **Print it first** to check the snap.
- `01_hip_mount_plate`: the lumbar-belt plate with the joint-1 ball and its four pegs. Its tab pushes into the stand
  post.
- `11`–`16` `_vertebra_N`: one per joint, root to tip. Number 6 carries the rounded foam tip.
- `99_display_stand`: floor plate and post. It's also fine to print it on the FDM printer in PETG.

## Print settings

- **Layers:** 0.03–0.05 mm. Solid, no hollowing (the parts are small and thin-walled).
- **Orientation:** stand each vertebra on its socket end (cup facing down), tilted 20–30°, with light supports on the
  outside only. Keep supports out of the cup and off the ball.
- **Snap tuning:** the ball-to-socket radial clearance is 0.08 mm (`mclear` in `cad/openscad/mini_kit.scad`).
  - Balls won't click in: raise it to 0.10–0.12.
  - Joints are floppy: lower it to 0.05.
  - Then re-export: `PYTHONPATH=. ~/.venvs/costumebipedaltail/bin/python cad/export_replica.py`.
- **Post-processing:** wash and cure gently. Over-cured ABS-like resin cracks at the cup slits.

## Assembly

1. **Thread the twine.** Use 0.8–1.0 mm waxed polyester or cotton twine (bores are Ø1.3 mm), about 30 cm.
   - Knot it at the top exit of the hip-mount boss.
   - Thread it through the ball of joint 1, each vertebra in order, and out of the tie-off hole under vertebra 6.
   - Leave it slack for now.
2. **Click the joints together.** Press each ball into the next vertebra's cup, going root to tip; the three slits
   let the cup open. Check that each joint swivels freely.
3. **Fit the elastics.** Each joint takes four orthodontic elastics (dorsal, ventral, left, right): **24 in total,
   plus spares**.
   - Each band hooks over a peg on the parent vertebra and the matching peg on the child's socket ear.
   - Peg-to-peg spans per joint (mm): J1 4.9, J2 6.0, J3 5.4, J4 4.5, J5 5.8, J6 5.7.
   - **1/8" (3.2 mm) medium-force orthodontic elastics** stretch to that length with light tension. Use 3/16" light
     elastics if 1/8" pull the joints stiff.
   - All four bands on a joint must be the same size, so the tail sits in its designed S-curve.
4. **Tension the twine.** Pull it snug and tie it off under vertebra 6. It holds the balls seated, just like the
   full-size cord.
5. **Mount it.** Push the hip-plate tab into the stand post. Swing the tail and let go: the elastics centre it, as the
   springs do on the full-size tail.

At this scale gravity is negligible next to the elastics' pull. That's why the kit uses four balanced bands per joint
instead of the full-size three (dorsal + left + right, where the dorsal spring also carries the tail's weight).

## Shopping list for the kit

| Item | Qty |
|---|---|
| ABS-Like Pro 2 resin | ~40 ml (tail + hip plate ~6 ml; the stand is ~30 ml, or print it in PETG) |
| Orthodontic elastics 1/8" medium (and a few 3/16" light) | 1 pack of 100 |
| Waxed twine 0.8–1.0 mm | 30 cm |

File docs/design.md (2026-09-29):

# Mechanical design

Completely passive tail for a 5 ft 8 in (1.727 m) performer. Nothing is powered. The performer's pelvis drives the
root, and springs, friction, gravity and inertia do the rest. Numbers here come from `cad/geometry.py` (the single
dimensional spec) and the physics results in `results/`. `docs/physics.md` explains why each element exists.

## Architecture

```text
 harness plate ── hip mount ──(ball 1)── V1 ──(ball 2)── V2 ── … ── V8 ── tip adapter ── 200 mm foam tip
                   │  arms                 │ fins              │ fins
                   └── 3 springs ──► cap-1 ears    └── 3 springs ──► cap-2 ears   …
 central 6 mm cord: stopper knot in a Ø26 mm knot chamber inside the hip-mount boss (loose end down a rope tunnel) → through every ball centre → tip compression spring
```

- **8 ball-and-socket joints** at 150 mm pitch: 1200 mm articulated, plus a 200 mm flexible foam tip = 1400 mm.
- **Taper:** envelope D(u) = 70 + 120(1 − u)^1.3 mm (190 → 70 mm). The frame (skin former) sits inside a foam
  skin 20 → 4 mm thick.
- **Ball** (on the parent) radius = 0.15 D, clamped 17–28 mm. The **socket seat** is part of the next vertebra's
  frame; the **bolted cap** captures the ball. This is the README's "two-piece bolted socket".
- **Angular stops** are an elliptical cone cut in the cap mouth: yaw limit × pitch limit (pitch = 0.7 × yaw),
  progressive 8° → 28°, with a 0.8 mm felt/rubber pad.
- **Roll key:** a screw whose head is captured inside the ball protrudes 3 mm from the dorsal pole into a
  meridional slot shared by seat and cap. The slot is long in pitch, the screw spins freely about its own axis in
  yaw, and the slot width limits roll to ±7°.
- **Spring spine:** three extension springs per joint (dorsal + left + right).
  - Parent end: a hole 4 mm from the distal fin edge of the previous vertebra (or a hip-mount arm).
  - Child end: an **ear on the socket cap, 5 mm proximal of the pivot**.
  - The dorsal spring carries the tail's weight moment; the lateral pair gives the yaw centring that makes the tail
    swing back.
- **Central cord** through every ball centre. It preloads the seats, sets joint friction and holds the chain
  together if a part fails. It is **not** a bending element: at the ball centres its length does not change with
  bending.
- **Frame:** socket housing + spine tube + four longitudinal fins (dorsal, ventral, left, right) with 45° diamond
  windows, a mid-length skin ring and a distal base ring.

### Why the child spring anchor is on the cap (twist stability)

A tensioned spring whose two anchors straddle a ball joint has a geometric stiffness in the yaw–roll plane of
roughly

    K_yaw,roll ≈ (T/ℓ) · [ (a_c² − a_p·a_c)  −a_c·w ;  −a_c·w  w² ]

Here T is the spring tension, ℓ its length, w its radial offset, and a_p and a_c the axial positions of the parent
and child anchors (distances measured distally from the pivot, so the parent anchor sits at −a_p).

- The determinant is −a_p·a_c·w² (T/ℓ)². If the child anchor is **distal** of the pivot (a_c > 0), the matrix is
  indefinite: a saddle. When roll is free, the heavily preloaded dorsal spring (up to 150 N at the root) then acts
  as a **negative** yaw spring of −T·a_p·a_c/ℓ.
- This showed up in the linearised model as a negative-frequency twist mode, and in the time domain as the tail
  slowly corkscrewing away from centre after a hip snap. That's the README's "uncontrolled twisting".
- Moving the child anchor 5 mm *proximal* of the pivot (a_c < 0, on the cap) flips the sign. The same springs then
  centre the joint, and the lowest mode became stable with no extra hardware.
- `docs/physics.md` has the numbers; the spring design routine keeps a linear-stability guard.

## Performer fit (5 ft 8 in)

| Quantity | Value |
|---|---|
| Pelvis (sacrum) height | 0.55 × 1727 ≈ 950 mm |
| Harness plate | 120–128 mm behind the pelvis centre, 190 × 150 mm, M6 slots on a 150 × 100 mm pattern + one 50 mm webbing slot, hex lightening holes |
| Joint 1 centre | 200 mm behind the pelvis centre |
| Root pitch | tail leaves the hip 15° nose-down, then droops 1.5° per joint |
| Rest tip height | ≈ 0.4 m above the floor (`results/data/study_metrics.json`, `min_tip_height`) |
| Tail length / stature | 1400 / 1727 = 0.81 (classic suitmation proportion) |

The load path is harness plate → hip mount → ball 1. No load goes into the costume foam. At rest the harness
carries about 25 N and a ~10 N·m pitch moment. It should be a rigid hip plate or backpack frame with a waist belt,
not soft foam.

## Parts per vertebra

| Printed | Hardware |
|---|---|
| `body_i` (frame + seat), `cap_i`, `ball_(i+1)` left/right halves (tip adapter for i = 8) | 8 × M4 × 16 + nylocks, 1 roll-key screw, 3 springs, felt liner |

A backstage repair of a broken ball or cap is: remove 4 cap bolts, unhook 3 springs, slack the cord at the tip,
swap the part. No glue is structural.

## Strength

`docs/tables/strength.md` (generated from the as-built simulation of every standard motion) gives:

| Element | Worst case | Capacity | Safety factor |
|---|---|---|---|
| Ball necks (hollow PETG tubes, cord bore Ø8, layers along the axis in the clamshell halves) | J1: 6.4 N·m = peak ball moment 4.4 N·m + 59 N lateral × neck length | 42.8 N·m at 20 MPa | ≥ 4.9 on every joint |
| Cap ears (10 mm PETG, out-of-plane load) | J1 dorsal spring: 218 N peak → 15 MPa | 45 MPa UTS | 3.0 |
| Fin anchor holes | Bossed to fin + 4 mm | — | — |
| Axial seat compression | ≤ 281 N → < 1 MPa on the neck | — | negligible |

Not covered by simulation: someone stepping on the tail, or a hard wall strike. Those are what drop tests 7–8 in
`docs/test_plan.md` are for. If the J1 ear or a root neck cracks there:
- print the J1–J3 ball halves and caps at 100 % infill (already recommended), or
- split the J1 dorsal spring into two springs on two ears.

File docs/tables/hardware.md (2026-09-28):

# Same built tail, one setting changed

Springs frozen at the as-built design (CAD masses); only the listed setting changes, as a builder would adjust it backstage. Columns as in study.md.

| configuration | snap lag | snap overshoot | oscillations | settle | residual | turn overshoot | walk whip 1.5/2.0 | peak tip v | max roll | crouch min tip z | crouch floor N | lowest mode Hz | score |
|---|---|---|---|---|---|---|---|---|---|---|---|---|---|
| as built (CAD masses, cord 10 N, felt, COM 15 mm) | 38.6 | 10.3 | 1 | 1.91 | 0.0 | 28.7 | 1.61 / 1.27 | 3.13 | 7.2 | 0.41 | 0.0 | 0.320 | 12.7 |
| as built, preload 5N | 38.8 | 10.4 | 1 | 1.91 | 0.0 | 29.0 | 1.61 / 1.27 | 3.16 | 7.2 | 0.41 | 0.0 | 0.320 | 13.5 |
| as built, preload 20N | 38.2 | 10.1 | 1 | 1.89 | 0.0 | 28.1 | 1.61 / 1.27 | 3.07 | 7.2 | 0.41 | 0.0 | 0.320 | 11.3 |
| as built, preload 40N | 37.6 | 10.0 | 1 | 1.86 | 0.0 | 26.8 | 1.61 / 1.27 | 2.96 | 7.2 | 0.41 | 0.0 | 0.320 | 8.7 |
| as built, friction VERY LOW | 49.8 | 41.1 | 2 | 3.69 | 0.1 | 66.3 | 1.58 / 1.45 | 6.42 | 7.8 | 0.41 | 0.0 | 0.320 | 476.5 |
| as built, friction LOW | 44.0 | 20.5 | 1 | 2.52 | 0.0 | 48.7 | 1.61 / 1.26 | 4.87 | 7.6 | 0.41 | 0.0 | 0.320 | 123.5 |
| as built, friction HIGH | 35.5 | 10.1 | 1 | 1.84 | 0.0 | 22.6 | 1.62 / 1.28 | 2.81 | 7.2 | 0.41 | 0.0 | 0.320 | 2.4 |
| as built, com 0mm | 38.7 | 9.2 | 1 | 2.11 | 0.0 | 27.5 | 1.57 / 1.26 | 3.10 | 7.2 | 0.39 | 0.0 | 0.291 | 10.0 |
| as built, com 30mm | 38.3 | 11.2 | 1 | 1.74 | 0.0 | 29.6 | 1.66 / 1.29 | 3.15 | 7.2 | 0.42 | 0.0 | 0.343 | 15.0 |
| as built, roll free | 38.6 | 5.7 | 1 | 1.59 | 0.0 | 11.2 | 1.61 / 1.27 | 3.00 | 9.7 | 0.41 | 0.0 | 0.320 | 0.0 |

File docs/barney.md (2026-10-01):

# Barney-style tail (client revision): the design to build

## Client brief (revision)

- **Length:** half the previous tail's length.
- **Shape:** a Barney-like tail, roughly an x³ profile. It sticks out a little at the back, goes down, then points
  back again.
- **Follow-up:** the end should stick out more, like a reverse sigmoid: start up, go down, then flatten out. The
  first S-curve ended ~35° nose-down, like a hill, because it only levelled off in the non-bending foam tip.
- **Mounting:** on a pharmacy lower-lumbar support belt, attached directly or hanging down from it.
- **Mechanics:** as approved in the Gojira variant (ball-and-socket chain, spring spine with cap-ear anchors, felt
  liners, cord, wedge-flange rest curve).
- **Scope:** this replaces both earlier variants, the life-size STLs and the 1:8 resin replica.

## Design

| Item | Value |
|---|---|
| Length | **0.90 m**: 0.75 m articulated (6 joints × 125 mm) + 0.15 m foam tip (half the 1.8 m Gojira tail) |
| Envelope | 190 mm at the root → 100 mm at vertebra 6 → 60 mm rounded foam tip (linear taper: fat, Barney-like) |
| Rest shape | **Reverse sigmoid** z = h − 0.35 m / (1 + e^−(x − 0.28 m)/0.05 m): leaves the back nearly level (root pitch 6.2°), dips at up to ~58° mid-tail, then flattens so the last vertebra and foam tip stick straight back. Wedge-flange rest bends +29.2°, +22.7°, -3.7°, -30.6°, -20.9° |
| Mount | Plate on the lumbar belt's back panel; the tail pivot **hangs 70 mm below the plate centre** (pivot 30 mm below the pelvis centre). One printed part does both "attach directly" and "hang down" |
| Belt attachment | Four 5 × 28 mm slots for 25 mm hook-and-loop straps around the belt's back panel, plus a top 50 mm webbing slot (the old bottom slot sat under the boss). Hex lightening holes in the plate. Add a 3 mm EVA pad behind the plate for comfort on the curved lower back |
| Mechanics | As approved: ball-and-socket + dorsal/left/right extension springs on cap ears + felt liners + 5–10 N cord + roll key |
| Tuning for the short tail | Spring dead band 6° (softer centring springs; a short tail is livelier). Round cap stop openings (pitch travel = yaw travel) so the tail's own weight can't hammer the stops on a jump landing. Minimum ball radius 22 mm for neck strength |

## Simulated behaviour

As built: the moving masses are measured from the exported STLs plus hardware, foam and skin, and the springs are
sized for them.

| Test (as built) | Result |
|---|---|
| Rest (standing) | tail ends pointing back, skin **52 cm** above the floor |
| 30° hip snap | lag 34°, overshoot 9°, 1 swing-back, settles in 1.2 s |
| Jerk left (30° in 0.25 s) | lag 40°, overshoot 8° |
| 45° dramatic turn | overshoot 31° |
| Walking 1.5 / 2.0 steps/s | tip/hip 1.95 / 1.78 |
| Crouch (−150 mm, 10°) | min clearance 47 cm |
| Side step 300 mm | min clearance 50 cm |
| Bending over 45° | tail lifts; hip moment 7.4 N·m |
| Jump (25 cm) | no floor contact; hip moment 14.2 N·m |
| Peak moment on the lumbar belt (any test) | 14 N·m |

Figures:
- `results/figures/barney_*.png`: hip snap, turn, jump, bend over, walking.
- `barney_hip_snap_waterfall.png`: the swing travelling root → tip.

Data: `results/data/barney.json`.

### Why these three tuning changes (found in simulation, not guessed)

1. **Softer centring springs (dead band 3.5° → 6°).** The half-length tail has fewer, lighter segments, so with the
   Gojira spring rule it overshot the hips by ~31° with two swing-backs. At 6° it overshoots
   9° with one swing-back.
2. **Round stop openings.** On a 25 cm jump landing (~2.4 g) the short, stubby tail bottomed out on its pitch stops
   at every joint, putting 11–23 N·m through the ball necks. Matching pitch travel to yaw travel cut the stop torque
   from 23 to 7 N·m.
3. **Minimum ball radius 17 → 22 mm.** This brings every neck to SF ≥ 3.5 against the simulated loads; the sharper reverse-sigmoid bends load joint 5 hardest.

The comparison of mechanisms on the hover profile (rigid gate hinges, elastic tube, stop-held chains; see
[gojira.md](gojira.md)) still applies. The spring-spine ball chain is the only one that is both compliant and
self-centring.

## Measured stop angles (finding, 2026-09-30)

On the exported meshes, the PETG neck-to-cap contact angle of the rest-bent joints depends on direction, because
the wedge neck turns toward the parent axis just outside the cap. For example, J5 meets the cap at 16.4° pitching
up, but pitching down nothing touches until about 32–40°; the design and the simulation use ±22°. The TPU
bumper rings restore the design stop everywhere except J5/J6 pitch-down. Details:
[tpu_bands.md](tpu_bands.md#pre-existing-finding-the-stops-on-rest-bent-joints-dont-match-the-design).

## Build files

| What | Where |
|---|---|
| Print-ready STLs (32 parts, 1.92 kg PETG) | `cad/stl/barney/`; list in [tables/barney_parts.md](tables/barney_parts.md) |
| OpenSCAD (generated variant of the parametric model) | `cad/openscad/suit_tail_barney.scad` |
| FreeCAD + STEP | `cad/freecad/output/suit_tail_barney.FCStd`, `.step` |
| Springs / strength / mass | [tables/barney_springs.md](tables/barney_springs.md), [tables/barney_strength.md](tables/barney_strength.md), [tables/barney_mass_budget.md](tables/barney_mass_budget.md) |
| 1:8 snap-together resin kit | `cad/stl/replica_1to8_resin/` (README there) |
| 1:8 protogen figurine with the adjustable-height plate slot | `cad/stl/figurine_1to8_resin/` (README there) |
| CAD renders, pose renders, photos | `results/cad_renders_barney/`, `results/pose_renders/`, `results/simulated_photos/` |

The whole tail is only 6 joints, so it *is* the prototype. There is no separate 4-joint test section; run the
measurements in [test_plan.md](test_plan.md) on the complete tail.

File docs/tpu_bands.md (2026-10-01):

# Printed TPU 95A parts for the Barney tail: spring straps, felt substitutes, washers

The extension springs were delayed, there's no felt, and the flexible filament on hand is **TPU 95A** (plus
64D, which is far too hard to act as a spring). Everything here prints in **95A with a 0.4 mm nozzle**. Nothing
already built needs reprinting.

| What | Print file(s) | Replaces |
|---|---|---|
| 24 straps (18 spring positions), labelled | `cad/stl/barney_tpu_bands/plate_all_straps.stl`: **one plate, print once** | the 18 extension springs |
| 12 spare straps, +10 % preload | `cad/stl/barney_tpu_bands/plate_tight10_spares.stl` (optional) | rest-pose trimming |
| 6 seat liner webs | `cad/stl/barney_tpu_liners/plate_seat_liners_part1of2_print1x.stl` + `..._part2of2_print1x.stl` | 0.5 mm felt in each socket seat |
| 6 cap-mouth bumper rings | `cad/stl/barney_tpu_liners/plate_mouth_rings_print1x.stl` | 0.8 mm felt stop pads |
| 132 M4 tension washers | `cad/stl/barney_tpu_liners/plate_washers_M4_132x_print1x.stl` | backup for the nylon washers |

- Single parts are in the sub-folders.
- Generators: `cad/tpu_bands.py` (straps) and `cad/tpu_liners.py` (liners, rings, washers).
- Checks: `cad/check_tpu_bands.py`, `cad/check_tpu_liners.py`, and `tests/test_tpu_*.py`.
- Simulation: `experiments/tpu_band_sim.py` → [tables/tpu_band_sim.md](tables/tpu_band_sim.md).
- Strap schedule: [tables/tpu_bands.md](tables/tpu_bands.md).

straps
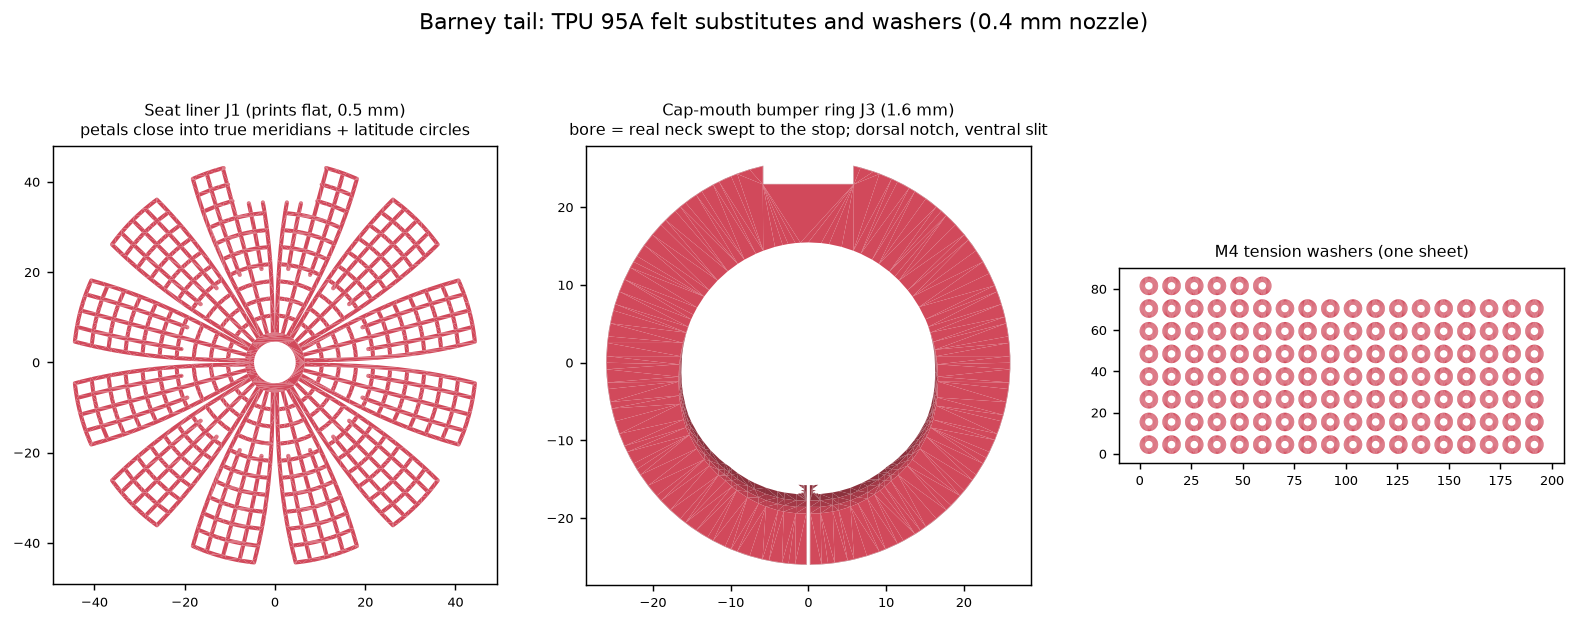
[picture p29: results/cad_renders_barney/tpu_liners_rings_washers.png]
liners, rings, washers


## Why a 0.4 mm nozzle

A strap has no built-in preload like a spring, so it must sit pre-stretched by T0/k at the rest span. That ratio
comes from the spring schedule, not the material. For 95A the stiffness then depends on how *small* a section
can be printed:

| Nozzle | Smallest strap section | Positions where 95A matches the spring rate |
|---|---|---|
| 1.2 mm | 3.0 × 1.2 mm | 2 of 18 (the rest 1.2–4× too stiff) |
| 0.6 mm | 2.4 × 0.9 mm | 6 of 18 |
| **0.4 mm** | **1.8 × 0.6 mm** | **15 of 18** |

The three exceptions are the high-preload dorsal positions:
- J1 dorsal is 2.0× stiffer, J4 dorsal 2.5× and J5 dorsal 1.65×.
- Matching them would need more than 25 % rest strain, which is past 95A's knee, where it creeps and sets.
- Their preload (T0) is still exact, so the rest pose is right; those joints are simply stiffer in pitch.

## Straps

- **Dorsal springs:** a pair of identical straps, one on each face of the cap ear and the fin (or hip-mount arm).
- **Lateral springs:** one strap, on the face the pull leans toward.
  - The rest-curve wedges tilt the parent fin by up to 30°, so a far-side strap would have to pass through the
    ear.
- **Mounting:** M4 bolts through the existing 4.5 mm spring holes.
- **Spacer pads:** printed on the eyes. They clear the flared ear and the ear's corner at full yaw.
- **Label tab:** at the **fin / hip-arm end**, debossed:
  - `3D`: joint 3 dorsal (pair).
  - `3L-T` / `3R-B`: joint 3 left or right lateral, on the **top** (dorsal) or **bottom** (ventral) face of the
    ear and fin.
  - A trailing `+` marks a tight spare.
- **Fit check:**
  - Strap, spacers, label tab, washers, bolt heads and nylocks were checked against the printed part meshes at
    rest and at ±yaw and ±pitch limits.
  - The worst case is a 0.4 mm³ graze at a full-bend stop.
- **Bolts:** M4 socket head with a washer each side plus a nylock: 12 × M4×25, 17 × M4×30, 6 × M4×35, 1 × M4×40.
  The fit check assumed 0.8 mm washers, which matches the TPU washer sheet.

| Check | Result |
|---|---|
| Preload T0 | equals the spring on all 18 positions |
| Rate k | equal on 15 positions; J1 dorsal 2.0×, J4 dorsal 2.5×, J5 dorsal 1.65× |
| Force at the angular stop | below the springs except J1 dorsal (158 vs 146 N) and J4 dorsal (55 vs 50 N) |
| Peak tension over every simulated motion (jump included) | J1 dorsal 180 N (springs 148 N). Cap-ear bending safety factor 9.2 (springs 11.2) |
| Strap stress | 7–10 MPa at the stops, about 10 MPa at the J1 peak: well under 95A's ~30 MPa strength, but near its knee, so expect a little set after hard stops (use the `+` spares) |

## Felt substitutes: is TPU good in the joints? Yes, with one caveat

The simulation decided it: [tables/tpu_band_sim.md](tables/tpu_band_sim.md), all cases with the 95A straps.

| Seat surface | Snap overshoot | Settle | 45° turn overshoot | Peak belt moment |
|---|---|---|---|---|
| Felt liner (design, μ 0.25) | 9° | 1.25 s | 32° | 21.6 N·m |
| **TPU liner web (μ ≈ 0.45)** | **11°** | **0.76 s** | **25°** | **13.2 N·m** |
| Bare PETG (μ 0.12) | 24° | 3.61 s | 53° | 41 N·m |

- **Bare PETG** isn't just noisy: the tail swings much more and loads the belt three times as hard.
- **The TPU liner's** extra friction calms the stiffer straps. It is the best of the three.

### Seat liner web (one per joint, prints flat)

- **Shape:** a hub ring round the cord bore, plus 12 petals.
- **The mapping:** a point on the seat sphere (angle θ from the pole, longitude φ, petal centre φₖ) is printed
  at flat radius R·θ and angle φₖ + (φ − φₖ)·sin θ/θ.
  - So every latitude strand prints at its **true** length R·sin θ·Δφ, and every petal-centre meridian at its
    true length R·Δθ.
  - Pressed into the seat, the petal edges close up. The latitude strands join into whole circles and the
    meridians run pole to rim.
  - The largest leftover stretch anywhere in the web is **1.1 %**, which TPU takes up without noticing.
- **Strands:** 0.9 mm (two lines), on a 3.5 mm grid, 0.5 mm thick (two 0.25 mm layers). That is the felt
  thickness the seat was sized for, leaving 0.4 mm running clearance.
- **Roll-key slot:** the dorsal seam stays open over it.
- **Fitting:** drop the web into the vertebra body's seat, hub over the cord bore and petals up the wall, before
  setting the body onto its ball. The ball holds it in place.

### Cap-mouth bumper ring (one per joint)

This is the part that stops the clank: it's where the neck hits the cap at the end of each swing.
- **What it is:** a flat 1.6 mm split ring. Glue it to the cap's outer face around the mouth with CA or contact
  cement.
- **Bore:** cut from the real neck geometry, the union of the ball's sections through the ring, swept over every
  bend direction up to that direction's stop.
  - Within the stop, the ring touches nothing.
  - At the stop, the neck lands on TPU.
- **Mesh check** (`cad/check_tpu_liners.py`, 8 directions per joint):
  - 0.3° inside the stop: no contact with the neck or the parent flange's bolt heads.
  - 1° past it: the neck is into the TPU, and the PETG rim is still clear.
- **Fitting:**
  - Open the ventral slit, slip the ring round the neck and glue it down.
  - The dorsal notch goes over the roll-key slot.

### Pre-existing finding: the stops on rest-bent joints don't match the design

The ball necks carry the rest-curve wedge, which turns the neck toward the parent axis just outside the cap.
Because of that, the real PETG neck-to-cap contact angle depends on direction:

| Joint | Design stop | PETG contact, measured on the meshes |
|---|---|---|
| J1 | 8° | 10.7° all round (as designed, with the 0.8 mm pad gap) |
| J2 | 11° | 11.3° pitch-down … 16.8° pitch-up |
| J3 | 14° | 13.5° pitch-down … 20.5° pitch-up |
| J4 | 18° | 19.6–21.7° |
| J5 | 22° | **16.4° pitch-up**; pitch-down: no contact until about **32–40°** (ball against cap) |
| J6 | 26° | **21.8° pitch-up**; pitch-down: no contact until about **40°** |

- **What the rings cover:** in every direction they put the stop back at the design angle, or 1.5° before any
  early PETG contact.
- **What they can't cover:** J5 and J6 pitching down, where the neck leans away from the cap face. Nothing on
  the cap face can reach it there; a taller ring that still prints without supports doesn't reach it either.
- **What holds those directions now:** only the dorsal straps or springs, until the ball hits the cap at
  32–40°.
- **Effect:** hard jump landings may still knock there. The fix is a CAD change (cap or wedge geometry) in a
  later revision.

## TPU M4 washers

- **Size:** 9 mm OD, 3.7 mm bore (snug on the M4 thread, so it stays put and acts as a light lock and spring
  washer), 0.8 mm thick.
- **Count:** 24 cap bolts and 24 ball-flange bolts (under the heads) plus 72 at the strap bolts (one each side)
  is 120. With 10 % spares that's 132, all on one sheet, printed once.
- **Under cap and flange heads:** the extra 0.8 mm still leaves the M4×16 bolts fully through their nylocks.

## Printing (Ender 3 V2, Sprite Pro, 0.4 mm nozzle, TPU 95A)

| Setting | Value |
|---|---|
| Layer | 0.2 mm for straps, rings and washers; 0.25 mm for the liner webs (two layers) |
| Speed | 20–25 mm/s (first layer 10–15) |
| Temperature | 225–235 °C nozzle, 50 °C bed; glue stick on PEI as a release layer |
| Retraction | ≤ 1 mm, slow; or off |
| Walls | enough to make each strap all perimeters (5–6 walls); infill 100 % |
| Supports | none (every part is flat or self-supporting) |

## Coupon calibration (optional, about 30 min, makes the forces trustworthy)

The straps use a nominal 95A curve; brands differ by up to 3×.
1. Print `calibration/coupon_tpu95a.stl`.
2. Stretch it 10 times to about 72 mm pin-to-pin.
3. Hang it from a bolt, and measure the pin-to-pin length (outside of the bolts minus 4 mm) with an empty bag,
   then with 1, 2 and 3 kg. Read each after 30 s.
4. Write `cad/tpu_calibration.json`:
   ```json
   {"tpu95a": {"width": 4.0, "thickness": 1.2, "points": [[0, 63.5], [1, 66.9], [2, 71.0], [3, 76.2]]}}
   ```
   (Example numbers; use your measured width and thickness.)
5. Run `PYTHONPATH=. python cad/tpu_bands.py --calib cad/tpu_calibration.json`. This rewrites all straps and
   plates and re-runs the fit check.

## Installing

1. **Break in each strap:** 10 stretches to its "break-in" length in the schedule.
2. **Seat liners:** fit one into each body's seat before that body goes onto its ball.
3. **Bumper rings:** glue one onto each cap face once the cap halves are bolted.
4. **Strap bolt stack:**
   - Dorsal pair: head, washer, strap (pad toward the ear), ear, strap, washer, nylock.
   - Lateral strap: head, washer, ear, strap on the labelled face, washer, nylock.
   - The label tab end goes on the **fin / hip arm**.
5. **Fitting the heavy dorsal straps:** cap end first, with the joint pitched up against its stop. Pull the eye
   over with a screwdriver shaft through it.
6. **Leave the eyes free to swivel:** snug each nylock, then back it off ¼ turn.
7. **Trim the rest pose:** the tail end should sit level, sticking straight back, with skin about 52 cm off the
   floor. Swap a sagging joint's dorsal pair for its `+` spare.
8. **When the springs arrive:** unbolt the straps and hook the springs into the same holes, using
   [tables/barney_springs.md](tables/barney_springs.md). Keep the liners, rings and washers.

## Caveats

- **Creep:** 95A loses some preload over hours, more after hard stops. Check the tail end's height between
  wearings and carry the `+` spares and a hex key.
- **Heat:** don't leave the tail tensioned in a hot car (TPU softens above about 40 °C).
- **J5/J6 pitch-down stop:** see the pre-existing finding above.

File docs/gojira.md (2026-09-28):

> **Superseded** by the client's Barney revision ([barney.md](barney.md)). The Gojira CAD, STLs and renders were removed; the mechanism comparison below is kept because the approved mechanics came from it.

# Gojira profile ("x² + 1"): which tail is cheapest and simplest?

**Target shape.**
- The tail leaves the hips pointing down, sweeps to a low point just *above* the floor (it hovers, never drags),
  and the tip curls slightly back up.
- Rest centreline follows z = c + a(x − x_v)² with c = 0.12 m, i.e. about 8–9 cm skin clearance at the low point.
- Solver: `tailsim/shape.py`.

**Length.**
- A 1.4 m tail can't make this curve from a 0.95 m hip. It would have to leave the hip at 68° and bend 27–45° per
  joint near the tip.
- The brief's long option works: **1.5 m articulated (10 joints × 150 mm) + 0.3 m foam tip = 1.8 m**.
  - The tail leaves the hip at 58°.
  - Every joint bend is ≤ 16°.
  - Heels clear the root at normal stride.

## Candidates (same shape, same masses, same hip inputs)

`experiments/gojira_compare.py`, `experiments/gojira_final.py`, and `results/data/gojira_final.json`:

| Mechanism | Snap lag (°) | Snap overshoot (°) | Swing-backs | Settle (s) | Turn overshoot (°) | Walk tip/hip (1.5 / 2.0 steps/s) | Rest clearance (cm) | Worst clearance: walk, turn, crouch (cm) | **Jump landing: floor force / hip moment** | Peak hip moment in snaps (N·m) |
|---|---|---|---|---|---|---|---|---|---|---|
| **Ball chain + spring spine** (this repo's design, reshaped) | 34.3 | 13.8 | 1 | 3.0 | 38.8 | 0.97 / 0.69 | 8.9 | −0.5 (foam brush, 0.8 N) | **20 N / 13 N·m** | 10 |
| Gate hinges, 60° tilt, damping grease | 25.3 | 16.5 | 2 | 3.1 | 22.6 | 1.25 / 0.67 | 9.0 | 5.8 | **861 N / 669 N·m** | 24 |
| Gate hinges, 45° tilt, damping grease | 28.8 | 18.9 | 2 | 4.8 | 26.6 | 1.08 / 0.65 | 9.0 | 5.8 | **842 N / 663 N·m** | 20 |
| Elastic spine (pre-cambered tube), 0.7 Hz | 32.4 | 0 | 1 | 0.0 | 0 | 3.26 / 0.57 | 9.0 | −3.4 (drags) | 46 N / 13 N·m | 11 |
| Elastic spine, 1.0 Hz | 32.6 | 0 | 1 | 1.4 | 22.6 | 1.01 / 1.89 | 9.0 | −2.9 (drags) | 46 N / 13 N·m | 11 |
| Ball chain resting on its pitch stops, lateral springs only | 33.1 | 0 | – | – | 0 | – | −0.2 (lies on floor) | – | – | – |
| Ball chain on pitch stops, no springs | 32.6 | 0 | – | – | 0 | – | −0.2 | – | – | – |

The jump is a counter-movement jump: the pelvis rises 25 cm, then drops 13 cm into a knee bend on landing.

### What each result means

- **Ball chain on its stops** (the cheapest articulated idea: no dorsal springs; the curve is set by stop angles).
  Stop friction freezes the yaw swing (it ends 29–38° off-centre) and the tail sags onto the floor. Rejected.
- **Gate hinges** (yaw-only hinge per joint, axis leaning back so gravity self-centres it like a self-closing gate;
  no springs, no cord, no roll key). This is the *cheapest and simplest* mechanism, and it swings well. It holds
  the curve rigidly, so clearance never changes.
  - **Rejected on safety:** being rigid in pitch, it cannot give when the tail meets the floor. A landing from a
    small jump drives the low point into the floor with **~860 N**, levering **~670 N·m** into the performer's
    pelvis. That is an injury-level load.
  - A stumble or fast crouch does the same.
  - Pitch compliance is not optional for a tail that hovers this close to the floor.
- **Elastic spine** (pre-cambered tube, e.g. twin stacked PEX, inside foam; no printed joints). Cheap and compliant.
  But with bending stiffness distributed along the length it cannot both hold the hover and swing freely: the low
  section brushes or drags, and floor friction kills the overshoot.
- **Ball chain + spring spine** is the only candidate that meets every requirement:
  - hovers at rest and in all tests (a 0.8 N foam brush in the most violent 45° turn only);
  - lags, overshoots and swings back once;
  - takes a jump landing gently (20 N, 13 N·m), because the dorsal springs let the tail ride up on contact.

## Recommendation: the optimal solution

**The ball-and-socket + spring-spine tail, reshaped to the Gojira profile**, with these simplifications (all
supported by the same-hardware study, `docs/tables/hardware.md`):

| Item | Decision | Why |
|---|---|---|
| Length / joints | 1.5 m, 10 joints at 150 mm, + 0.3 m foam tip | Needed to make the x² + 1 curve from a 0.95 m hip |
| Rest curve | Built into the parts: each ball flange printed on a **wedge** equal to that joint's rest bend (58° root, then −3 … −16° upward bends) | Springs then only carry weight about the designed curve, and stops stay centred |
| Springs | Keep dorsal + left/right per joint | Dorsal: holds the hover *and* is the pitch compliance that makes landings safe. Lateral: the swing-back |
| Spring anchors | Child end on cap ears, proximal of the pivot | Twist stability (docs/physics.md §2.4) |
| Seat liner | Felt (μ ≈ 0.25) | Main tuning knob; PTFE is too whippy |
| Central cord | Keep, but at only 5 N | Preload has almost no effect on motion; the cord is cheap retention insurance |
| COM ballast | Omit | Only a secondary effect |
| Roll key | Keep (one screw per joint) | Removing it halves the swing |

**Rough hardware cost** (commodity prices, excluding the foam skin):
- **Recommended ball chain:** ~$120–180.
  - Printed PETG: ~2.8 kg, ~$60.
  - Screws and nuts: ~$20.
  - 30 extension springs: ~$40–80 (the two root dorsal springs are the heavy ones).
  - Cord, felt: ~$10.
- **Gate-hinge chain:** would be roughly half that.
- **Elastic tube spine:** about a quarter.

The ball chain costs more, and the extra buys the pitch compliance the hovering Gojira tail needs.

## Final design as built (regenerated CAD, 10 joints)

The CAD was regenerated for this shape: `cad/variants/gojira.json`, `cad/openscad/suit_tail_gojira.scad`.

- **Exact CAD anchors:** the physics model was re-run with the CAD's spring anchor positions (parent anchors in the
  parent's own frame, as the fin holes are) and the wedge-flange neck lengths.
- **Raised design curve:** that made the tail settle ~2.5 cm lower, so the design low point was raised from 12 to
  14.5 cm on the centreline.
- **Real masses:** the tail was then simulated with the moving masses measured from the exported STLs, hardware and
  foam skin. That is **3.3 kg, against 2.2 kg assumed**, and heavier toward the tip; see
  [tables/gojira_mass_budget.md](tables/gojira_mass_budget.md).
- **Springs re-sized:** the springs were re-sized for those masses.
- **Geometry:** root pitch is 55°. The upward rest bends, printed as wedge flanges, are
  -2.4°, -2.9°, -3.6°, -4.4°, -5.5°, -7.0°, -8.8°, -10.5°, -11.6°.

| Test (as built) | Result |
|---|---|
| Rest (standing) | skin **8.6 cm** above the floor |
| 30° hip snap | lag 38.2°, overshoot 26.1°, 2 swing-backs, settles in 4.5 s; min clearance 3.3 cm |
| Jerk left (30° in 0.25 s) | lag 38.8°, overshoot 27.1° |
| 45° dramatic turn | overshoot 48.2°; foam brushes the floor at 1.8 N at the extreme of the swing |
| Walking 1.5 / 2.0 steps/s | tip/hip 1.08 / 0.85; min clearance 5.7 cm |
| Crouch (−150 mm, 10°) | min clearance 1.4 cm |
| Side step 300 mm | min clearance 3.5 cm |
| Bending over 45° | tail rises clear; peak hip moment 24.5 N·m |
| Jump (25 cm) | brief floor touch on the landing knee-bend, 26 N; hip moment 20.8 N·m |

What the extra mass changes:
- **More theatrical swing:** two swing-backs instead of one, and a larger overshoot.
- **Stronger springs:** the root dorsal springs need ~240 N at rest (two heavy springs in parallel at joints 1–4;
  see [tables/gojira_springs.md](tables/gojira_springs.md)).
- **Thicker cap ears:** 16 mm on the root caps. Every checked element keeps SF ≥ 3
  ([tables/gojira_strength.md](tables/gojira_strength.md)).

If the swing reads as too loose on the 4-joint prototype:
- first go from felt to a rubber seat liner, which adds friction;
- then lighten the distal vertebrae (two perimeters, 10 % infill), since they carry most of the excess mass.

Build files (the Gojira tail is the one to print):

| What | Where |
|---|---|
| Print-ready STLs, full tail (10 joints) | `cad/stl/gojira/`; list with sizes and masses in [tables/gojira_parts.md](tables/gojira_parts.md) |
| 4-joint prototype kit (joints 1–4 + ballast plate) | `cad/stl/gojira_test_section/` |
| OpenSCAD (parametric; generated variant file) | `cad/openscad/suit_tail_gojira.scad` (includes `suit_tail.scad`) |
| FreeCAD + STEP | `cad/freecad/output/suit_tail_gojira.FCStd/.step`, `test_section_4joint_gojira.FCStd/.step` |
| Springs, strength, mass | [tables/gojira_springs.md](tables/gojira_springs.md), [tables/gojira_strength.md](tables/gojira_strength.md), [tables/gojira_mass_budget.md](tables/gojira_mass_budget.md) |
| CAD renders (real parts; five simulated poses) | `results/cad_renders_gojira/` |

Printing notes specific to this variant:
- **Hip mount:** the root boss leaves the plate at 55°, so print it plate-down **with tree supports under the boss**.
  It is the only part that needs supports.
- **Ball halves:** each carries its joint's rest-bend wedge. Keep each ball with its joint number; they are not
  interchangeable.
- **Joint count:** there are 10 joints, so 10 caps, 10 bodies and 20 ball halves.

The finalist comparison above was computed with the first shape (12 cm design low point, 2.2 kg). Its conclusions
(rigid hinges are unsafe on landing, and the tube and stop-held chains fail the hover) do not depend on those
changes.

## Simulated photos

`results/pose_renders/` holds the physics-accurate renders. The tail shape at each instant comes from the simulation
of the recommended design; the performer mannequin is posed from the simulated pelvis motion.
`results/simulated_photos/` holds photoreal versions: Z-Image Turbo image-to-image at partial denoise, which keeps
the simulated geometry and camera.

| Pose (instant) | Physics render / photo / CAD render | Tail state (as built) |
|---|---|---|
| Standing still | `1_standing` | skin 8.6 cm above the floor |
| Bending over (pelvis pitched 45°, 3 s) | `2_bending_over` | tail rises as a counterbalance, 56 cm clear |
| Turning (45° in 0.5 s; largest sideways tail deflection) | `3_turning` | hips at 44°, tail at −9°: ~52° of lag |
| Jerk to the left (30° in 0.25 s) | `4_jerk_left` | hips at 30°, tail at −8° |
| Jump, 50 ms before landing | `5_jump_before_landing` | pelvis 10 cm above standing height, tail 23 cm clear |

The files are in `results/pose_renders/`, `results/simulated_photos/` (Z-Image Turbo image-to-image of the physics
render, denoise 0.55) and `results/cad_renders_gojira/` (the real exported STLs articulated with the simulated joint
angles).

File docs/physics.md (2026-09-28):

# Physics prototype: model, validation and findings

The question from the brief:

> When a human performer turns their hips, does this mechanism produce the exaggerated but physically believable
> secondary tail movement of traditional practical creature suits?

**Short answer: yes, but only with passive centring springs across each joint.**

A friction-only ball chain cannot swing back. The "no springs" run never follows the hip: it ends 33° off the
hip's heading and drags on the floor when crouching.

With the spring spine designed here, and the **as-built masses from the exported CAD**, the tail's response to a
30° hip snap in 0.35 s is:

| Metric | As built | README intent |
|---|---|---|
| Maximum tip lag behind the hip | 38.6° (tip first swings the *other* way as the root is carried sideways) | "tail mass lags behind" |
| Tip overshoot after the hip stops | 10.3° (34 %) | "tip overshoots" |
| Visible swing-back / oscillations | 1 | 1–2 decreasing oscillations |
| Settling (within 2°) | 1.9 s | settles |
| Residual offset | 0.0° | — |
| 45° dramatic turn overshoot | 28.7° | "tip swings noticeably" |
| Walking tip/hip yaw ratio (1.5 / 2.0 steps/s) | 1.61 / 1.27, no stop hits | visible but restrained |
| Crouch (−150 mm, 10°) | no floor contact, no binding | — |

Animations: `results/animations/as_built_*.gif`. Joint-yaw waterfall showing the wave travelling root → tip:
`results/figures/as_built_hip_snap_waterfall.png`. Tuning knobs, from the same-hardware study
(`docs/tables/hardware.md`):
- **The seat liner (friction) is the main knob.** PTFE instead of felt gives a whippy 41° overshoot with two
  oscillations; dry PETG gives 20°.
- **Cord preload barely matters** on built hardware (5 → 40 N changes overshoot by 0.4°).
- **Removing the roll key halves the swing.** The energy leaks into twisting.

## 1. Model (MuJoCo 3.13, `tailsim/`)

| Element | Representation |
|---|---|
| Pelvis | Kinematic "hip block" (80 kg, 6 DOF) driven along the prescribed path by a stiff PD servo with feed-forward (tracking error < 0.06°) |
| Vertebrae | 8 separate rigid bodies, each with its own mass, centre of mass (optionally offset below the axis) and a thick-tube inertia from the taper |
| Ball joint | Three serial hinges yaw → pitch → roll at the ball centre, each with its own soft limit (TPU/felt stop, 12 ms time constant) |
| Ball friction | Coulomb `frictionloss` on each hinge = μ · R_ball · \|F_ball\|. F_ball is recomputed every 2 ms from the actual ball reaction: the distal subtree's inertial and gravity load plus every tension crossing that joint (cord + springs) |
| Viscous damping | Small, scaled by distal inertia (felt/grease) |
| Central cord | Spatial tendon through every ball centre; tension-only spring/damper: T = max(0, T0 + k ΔL + c dL/dt) |
| Spring spine | Per joint, one dorsal and two lateral tension-only springs between the real CAD anchor points |
| Foam tip | Compliant 2-DOF body (0.6 N·m/rad) with soft floor contact |
| Floor | Plane at z = 0, soft contact, μ = 0.6 |

The geometry (ball radii, anchor positions and spring arms) is imported from `cad/geometry.py`, so the simulated
tail is the printable one.

## 2. Findings that changed the design

### 2.1 Friction alone cannot give the swing-back; a restoring stiffness is required

- A ball chain with only friction and stops has no preferred heading. After a hip snap it coasts until friction
  stops it, or until it slams into its stops.
- The "tip overshoots → tail swings back → 1–2 decaying oscillations" sequence in the README is the signature of a
  **spring–mass** system. Something has to store energy when the tail bends and return it.
- A cord through the ball centres can't do this, because its length does not change when a joint bends. The
  `naive_no_springs` configuration shows the result: the tail never swings back. It drifts, hangs on its stops and
  keeps whatever offset friction leaves it with. (Numbers in `docs/tables/study.md`.)

So each joint gets three tension-only extension springs:
- **Dorsal:** preloaded to carry the tail's weight moment.
- **Left and right:** an antagonistic pair giving yaw centring.

### 2.2 The dorsal spring must hold the tail up

The tail's weight moment at the root is ~9 N·m. Friction torque (μ·R·N ≈ 1 N·m) can't hold it, so without
support the tail sags onto its pitch stops. Once it rests on a stop, that stop's friction brakes the yaw swing.

The dorsal spring preload is set so that its generalized force cancels the gravity bias at the rest pose,
`T0 = −qfrc_bias / (dL/dq)`. This gives 147 N at joint 1, falling to ~9 N at joint 8.

### 2.3 Spring stiffness must beat the friction dead band

A Coulomb joint with a centring spring K stops anywhere within ±τ_f / K of centre. The springs are sized to the
larger of:

- an inertia rule, K = (2π · 0.7 Hz)² · I_distal
- a friction rule, K = τ_f / 3.5° (with τ_f from the static ball load, which includes the springs' own preload,
  hence the iteration)

The first attempt used only the inertia rule. After a hip snap the tail stuck 40° off-centre: at the tip the
friction torque was several times the spring torque.

### 2.4 Twist stability decides where the springs attach (the key CAD change)

A preloaded spring crossing a pivot has geometric stiffness. With the child anchor *distal* of the pivot, the
yaw–roll stiffness matrix of the joint is indefinite, with determinant −a_p·a_c·w²·(T/ℓ)². With roll free, the
150 N dorsal spring then acts as a negative yaw spring.

- **Linearised model:** the lowest mode of the whole tail was −0.28 Hz, i.e. statically unstable.
- **Time domain:** after the hip snap the tail kept corkscrewing slowly away from centre (tip heading 25° → 17° over
  4 s while roll crept to its ±7° stops). That's the README's "uncontrolled twisting".
- **Fix:** move the child anchor to an ear on the socket cap, 5 mm *proximal* of the pivot. The saddle becomes
  positive-definite, and the same springs now centre in both yaw and roll. The lowest mode of the reference design
  is +0.30 Hz.
- **Guard:** `TailSim._design_springs` also stiffens the lateral pair until the lowest linear mode is above
  0.1 Hz. It needed no extra stiffening for the reference design.

### 2.5 COM offset (gravity bias) helps roll, not yaw

- τ = m·g·r·sin θ acts about the **roll** axis. For yaw it only helps through the 15° root pitch.
- **Design study, 0 → 50 mm:**
  - The lowest (twist) mode stiffens from 0.18 to 0.31 Hz.
  - Snap overshoot grows from 1.4° to 4.9°, and the tail settles cleaner (residual 0.5° → 0°).
- **Same hardware, 0 / 15 / 30 mm:** overshoot 9.2° / 10.3° / 11.2°, settling 2.1 / 1.9 / 1.7 s.
- So a modest offset does help natural settling and twist resistance, but it is a secondary knob.
- 15 mm is the reference (ballast low in the frame, e.g. a steel washer on the ventral fin). 50 mm buys little and
  adds mass.

### 2.5a The roll key

- **Roll free vs roll key** (`roll_free_vs_roll_key.gif`, same hardware): the hip-snap overshoot drops from 10.3°
  to 5.7° and the turn overshoot from 28.7° to 11.2°. Roll reaches 9.7°.
- In the design study, D with unrestricted roll loses its overshoot entirely.
- Energy that should swing the tail goes into twisting the chain, so keeping roll at ±7° with the key is worth it.

### 2.6 The cord's job is retention, not motion

In a rigid-socket model a centred cord stores no bending energy. Its only effect is seat compression, and
therefore friction.

- **Same built tail** (`hardware.md`): cord preload 5 → 40 N changes the hip-snap overshoot only from 10.4° to
  10.0° and the turn overshoot from 29.0° to 26.8°. The ~150 N dorsal and ~15–20 N lateral spring tensions already
  dominate the ball load.
- **Design study** (`study.md`), where the springs are re-sized for each preload: higher preload leads to stiffer
  springs and *more* overshoot (0.8° → 10.6°).
- **Recommendation:** set the cord for retention only (5–10 N, slack taken up) and tune motion with the liner and
  springs. `min_seat_compression` stays positive in every test, so no ball ever lifts off its seat.

### 2.7 Walking vs. snap: frequency placement

- Pelvis yaw in walking repeats once per **stride**, i.e. at half the step rate (0.75–1.0 Hz for 1.5–2.0 steps/s).
- The tail's first swing mode sits below that, so walking drives it above resonance. Tip heading amplitude is
  1.3–1.8× the hip's in every spring configuration (no stop hits). A hip snap, being a transient, gets the full lag
  and overshoot.
- With the README-literal input (yaw at the full 1.75 Hz step rate) the tail barely follows (ratio ≈ 0.9).
- HIGH friction is the exception. There the springs are sized stiff enough to beat the friction, and walking whip
  rises to 2.7–3.1×.

### 2.7a Other study results (`docs/tables/study.md`)

- **Joint count:**
  - 10 joints scores slightly better than 8 (4.2° overshoot, turn 22.6°).
  - 6 joints is heavier-looking and more swingy (12° overshoot, turn 35°).
  - 12 joints begins to look snake-like and the tip hangs lower (crouch tip 0.33 m).
  - 8 is kept for part count.
- **Progressive vs uniform limits:** uniform ±16.9° limits (A–C) give 10–14° snap overshoot versus 2.7° for the
  progressive 8 → 28° set (D, README masses). The stiff root reins in the swing and keeps the bend near the tip.
- **Mass taper:** uniform 250 g segments overshoot 14° and walk with less tip motion. The README's aggressive
  taper gives a heavier-root, looser-tip look.

### 2.8 Mass budget: the distal end is heavier than the README guess

The printed + hardware + foam/skin mass per segment (`docs/tables/mass_budget.md`) is about 12 % over the README at
the root (507 vs 450 g) but 1.5–2.8× heavier toward the tip. The total is ~2.55 kg against the README's 2.0 kg. Two floors cause this:
- the minimum practical ball (Ø34 mm) with M4 bolts;
- two-line fins on a 150 mm segment.

The `cad_masses` / `as_built` configurations re-run every test with these masses, so the prototype is judged on its
real inertia. The heavier tip turns out to *help* the theatrical look: overshoot 2.7° → 10.3° and a clear
swing-back. Loads rise ~10 %, still within the strength margins (`docs/tables/strength.md`).

## 3. Validation (`tests/test_physics.py`, all passing)

1. **Static support:** with the dorsal springs sized from the gravity bias, the settled rest pose moves < 0.5° in
   pitch.
2. **Ball load:** the joint-1 ball force from MuJoCo's `cfrc_int` equals a hand vector sum (distal weight + spring
   and cord tensions) within 2 %.
3. **Energy:** with friction and damping removed and a rigid base, total energy (kinetic + gravity + spring + foam
   tip) changes by exactly the work of the soft limit constraints (within 1 % of the input kick). Every
   non-constraint force is conservative.
4. **Modal check:** the small-motion modes of the linearised model (spring geometry, gravity and foam tip) are
   compared with the time-domain simulation, each mode excited on its own from a settled equilibrium. Measured
   frequencies agree within 5 % for the two lowest stable modes.
5. **Time-step convergence:** hip-snap tip heading at dt = 0.5 ms vs 0.25 ms agrees within 1.5°.
6. **Hip tracking:** the prescribed pelvis path is followed within 0.2° during the 45° turn.
7. **Tension-only:** cord and spring tensions never go negative.
8. **Gravity bias:** the roll restoring torque equals −m·g·r·sin θ·cos(tilt) within 8 %.

These checks cover the model as written. They do not validate the friction law, spring rates or foam behaviour
of real parts. That is what the 4-joint test section is for (`docs/test_plan.md`).

## 4. Reproduce

```bash
python3 -m venv ~/.venvs/costumebipedaltail && ~/.venvs/costumebipedaltail/bin/pip install -r requirements.txt
PYTHONPATH=. ~/.venvs/costumebipedaltail/bin/python -m unittest -v tests.test_physics tests.test_cad
PYTHONPATH=. ~/.venvs/costumebipedaltail/bin/python experiments/sweep.py stage3      # tuning sweep
PYTHONPATH=. ~/.venvs/costumebipedaltail/bin/python experiments/run_suite.py         # study, plots, animations, CSV
PYTHONPATH=. ~/.venvs/costumebipedaltail/bin/python experiments/make_tables.py       # docs/tables/*.md
```

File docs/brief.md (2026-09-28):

# Project: Passive Mechanical Suitmation Dinosaur Tail

Design and simulate a **short, low-cost, completely passive mechanical dinosaur/monster tail** intended for a human performer wearing a bipedal creature suit.

The aesthetic and movement target is traditional practical-effects **suitmation**: a performer inside a bipedal dinosaur, kaiju, or monster costume with a relatively short, chunky tail attached around the hips.

Think in terms of the mechanical requirements of:

- classic kaiju / Godzilla-style creature suits;
- 1990s television dinosaur costumes;
- tokusatsu monster suits;
- low-budget practical creature effects.

This is NOT intended to reproduce the anatomy or tail length of a real theropod dinosaur.

It should look convincing on camera while being:

- inexpensive;
- lightweight;
- mechanically simple;
- rugged;
- repairable;
- printable;
- safe for a performer;
- completely passive.

There must be:

**NO motors.  
NO servos.  
NO electronics.  
NO pneumatics.  
NO hydraulics.**

The performer's body supplies all energy.

---

# 1. Primary Motion Goal

The tail attaches to a rigid or semi-rigid hip harness worn by the performer.

Movement of the performer's pelvis drives the root of the tail.

The desired sequence is:

```text
PERFORMER ROTATES HIPS LEFT
          ↓
TAIL ROOT MOVES LEFT
          ↓
TAIL MASS LAGS BEHIND
          ↓
CURVE PROPAGATES TOWARD TIP
          ↓
PERFORMER STOPS
          ↓
TAIL CONTINUES MOVING
          ↓
TIP OVERSHOOTS
          ↓
TAIL SWINGS BACK
          ↓
1–2 DECREASING OSCILLATIONS
          ↓
TAIL SETTLES
```

The result should have intentionally exaggerated practical-effects movement rather than robotic positional accuracy.

The principal engineering question is:

> Can a short chain of passive ball-and-socket vertebrae transform ordinary hip rotation and walking motion into convincing delayed tail movement?

---

# 2. Overall Tail Size

Initial target:

```text
mechanical_tail_length = 1400 mm
```

Allow adjustable range:

```text
1000–1800 mm
```

The last portion may eventually be a lightweight flexible foam tip rather than articulated machinery.

Initial mechanical section:

```text
approximately 1100–1300 mm
```

Optional foam extension:

```text
200–400 mm
```

Maximum individual module envelope:

```text
200 × 200 mm
```

No single rigid printed/manufactured component should exceed approximately 200 mm in its principal dimensions.

---

# 3. Vertebra Count

Initial configuration:

```text
joint_count = 8
```

Make configurable:

```text
6–12 joints
```

Do NOT begin with a 20–30 joint snake-like mechanism.

The desired design uses a relatively small number of substantial mechanical vertebrae.

Initial approximate center-to-center spacing:

```text
150–180 mm
```

---

# 4. Taper

The tail should taper aggressively.

Initial dimensions:

```text
root_diameter = 190 mm
mid_diameter  = 120 mm
last_mechanical_diameter = 70 mm
tip_diameter = 30–50 mm
```

Use:

```text
u = i/(N-1)
```

and a nonlinear taper:

```text
D(u) = D_tip + (D_root-D_tip)(1-u)^p
```

Default:

```text
p = 1.3
```

Expose `p` as a parameter.

The tail should visually read as:

```text
THICK ======================> thin
HIP                           TIP
```

rather than as a uniform snake.

---

# 5. Mechanical Architecture

Use a serial chain of ball-and-socket vertebrae:

```text
HIP HARNESS

    ||
    ||
 [ROOT]
    O
   ( )
    O
   ( )
    O
   ( )
    O
   ( )
    O
   ( )
    O
   ( )
    O
   ( )
    O
     \
      \___ lightweight tip
```

Each vertebral joint consists of:

- spherical male ball;
- partial spherical female socket;
- ball neck;
- central cord passage;
- optional friction liner;
- mechanical angular stop;
- lightweight structural shell/frame.

Use a **two-piece bolted socket** as the default physical construction.

---

# 6. Central Tension Cord

A continuous flexible cord runs approximately through the centers of all joints:

```text
HIP → O → O → O → O → O → O → O → O → TIP
```

Initial physical assumption:

```text
6 mm braided polyester cord
or
paracord
```

The cord provides:

- joint retention;
- adjustable compression;
- tunable joint friction;
- resistance to separation.

It MUST NOT be modeled as a rigid shaft.

For physics simulation, represent it as a:

```text
tension-only spring/damper
```

with configurable preload.

Initial preload tests:

```text
5 N
10 N
20 N
40 N
```

---

# 7. Progressive Joint Limits

Do NOT give every vertebra identical movement.

The root should be substantially stiffer and more restricted than the tip.

Initial target:

```text
Joint 1: ±8°
Joint 2: ±10°
Joint 3: ±12°
Joint 4: ±15°
Joint 5: ±18°
Joint 6: ±20°
Joint 7: ±24°
Joint 8: ±28°
```

These numbers must be parameters.

The result should behave approximately like:

```text
HIP

█████
    █████
        ████
           ███
             ██
               \
                \
                 \__
```

rather than producing sharp bends near the performer's body.

---

# 8. Degrees of Freedom

Each ball joint naturally provides:

```text
pitch
yaw
roll
```

Primary desired movement:

```text
YAW = strong
PITCH = moderate
ROLL = preferably restricted
```

The tail should primarily swing horizontally as the performer's pelvis rotates.

Provide optional parameters:

```text
max_yaw
max_pitch
max_roll
```

Example:

```text
yaw   = progressive ±8° to ±28°
pitch = approximately 70% of yaw allowance
roll  = ±5–10°
```

Also model a version with unrestricted roll for comparison.

---

# 9. Passive Gravity Bias

Test an optional center-of-mass offset below each ball-joint center.

Concept:

```text
      joint center
          O
          |
          |
         [m]
```

Gravity creates restoring torque:

```text
τ = m g r sin(θ)
```

where:

```text
m = effective vertebral mass
g = gravity
r = COM offset below pivot
θ = angular displacement
```

Test:

```text
COM offset = 0 mm
COM offset = 15 mm
COM offset = 30 mm
COM offset = 50 mm
```

Do NOT automatically assume that maximum gravity bias is desirable.

The purpose of simulation is to determine whether a modest COM offset improves natural settling and prevents uncontrolled twisting.

---

# 10. Mass Distribution

The tail should become dramatically lighter toward the tip.

Example starting values:

```text
V1 = 450 g
V2 = 400 g
V3 = 330 g
V4 = 270 g
V5 = 210 g
V6 = 160 g
V7 = 110 g
V8 = 70 g

foam_tip = 50–100 g
```

These represent complete moving segments, including estimated skin/foam.

All masses must be parameters.

The physics simulation must preserve each vertebra as a separate rigid body with its own center of mass and moment of inertia.

---

# 11. Friction and Damping

Provide configurable rotational friction/damping.

Test at minimum:

```text
VERY_LOW
LOW
MEDIUM
HIGH
```

The desired behavior is NOT critically damped precision machinery.

Some overshoot is desirable.

Ideal visual response:

```text
hip moves
    ↓
tail lags
    ↓
tail catches up
    ↓
tip overshoots
    ↓
small return swing
    ↓
settles
```

Target approximately:

```text
1–2 visible decreasing oscillations
```

after a sudden hip stop.

---

# 12. Hip Harness Interface

Represent the performer's pelvis as a kinematic rigid body.

The root of the tail attaches to this body.

Do not initially attempt to model the entire human body.

Use a simplified:

```text
HIP BLOCK
```

with:

```text
yaw
pitch
roll
XYZ translation
```

available as animation inputs.

Provide a root mounting plate suitable for eventual attachment to:

- backpack-style frame;
- waist belt;
- rigid hip plate;
- creature suit internal harness.

The mechanical load should ultimately be transferred to the performer's pelvis/torso harness rather than to costume foam.

---

# 13. Primary Physics Test — Hip Snap

Simulate:

```text
hip yaw:

0°
→ +30°
→ STOP
```

Perform the rotation over approximately:

```text
0.35 seconds
```

Then hold the hip stationary.

Measure:

```text
tip angular lag
tip displacement
tip velocity
overshoot
number of oscillations
settling time
maximum joint angle
```

This is the most important test.

---

# 14. Walking Simulation

Create simplified pelvis motion representing walking.

Approximate:

```text
yaw:
±5°

roll:
±3°

vertical translation:
±20 mm

frequency:
1.5–2.0 Hz
```

Observe whether ordinary walking creates subtle continuous tail movement.

The tail should NOT violently whip around during ordinary walking.

It should have visible but restrained secondary motion.

---

# 15. Dramatic Performer Turn

Simulate:

```text
pelvis yaw:

0°
→ +45°
```

over:

```text
0.5 sec
```

then stop.

Desired result:

```text
hips stop
tail continues
wave travels toward tip
tip swings noticeably
tip overshoots
tail returns
```

This represents a performer dramatically turning toward another character.

---

# 16. Side-Step Test

Translate pelvis:

```text
X = 0 → 300 mm
```

over:

```text
0.5 sec
```

then stop.

Measure lateral tail response.

---

# 17. Crouch Test

Move pelvis downward:

```text
150 mm
```

while pitching approximately:

```text
10°
```

Ensure that the tail naturally changes position without joints binding.

---

# 18. Safety / Floor Interaction

Include a simplified floor plane.

The tail should be capable of occasional floor contact without generating extreme joint forces.

Later physics iterations should investigate:

```text
tail-floor collision
friction
tip dragging
```

The foam tip should be treated as highly compliant.

Do not design a rigid pointed tip.

---

# 19. FreeCAD Deliverable

Create a fully parametric FreeCAD model using Python.

Suggested hierarchy:

```text
SuitTail
│
├── HipMount
│
├── Vertebra01
│   ├── Socket
│   ├── Ball
│   └── Frame
│
├── Vertebra02
├── Vertebra03
├── Vertebra04
├── Vertebra05
├── Vertebra06
├── Vertebra07
├── Vertebra08
│
├── CentralCord
│
└── FoamTipReference
```

Do not manually create eight unrelated parts.

Create a function resembling:

```text
createVertebra(index, parameters)
```

and generate all vertebrae procedurally.

---

# 20. OpenSCAD Deliverable

Create reusable modules:

```text
ball()
socket_half()
socket()
vertebra_frame()
vertebra()
hip_mount()
foam_tip_reference()
tail_assembly()
joint_motion_envelope()
```

Top-level parameters should include:

```text
joint_count
tail_length
root_diameter
tip_diameter
taper_exponent
cord_diameter
cord_preload
max_yaw
max_pitch
max_roll
```

Allow:

```text
PART = "assembly"
PART = "vertebra"
PART = "ball"
PART = "socket"
PART = "hip_mount"
PART = "section"
PART = "motion_envelope"
```

---

# 21. Physical Prototype

Before manufacturing the complete tail, generate a:

```text
4-JOINT TEST SECTION
```

approximately:

```text
600–700 mm long
```

using full-scale joint geometry.

This should be sufficient to test:

- ball/socket friction;
- cord preload;
- joint retention;
- gravity bias;
- angular stops;
- passive follow-through.

After validation, generate the complete eight-joint tail.

---

# 22. Cheap Construction Assumptions

Design around:

```text
PLA or PETG
TPU where useful
M4/M5 bolts
washers
nylock nuts
paracord/braided cord
commodity springs
felt
rubber
EVA foam
upholstery foam
```

Avoid:

```text
precision bearings
machined aluminum
custom gears
expensive spherical bearings
specialty actuators
```

unless simulation reveals a compelling reason.

The mechanism should be something that could realistically be repaired backstage with basic tools.

---

# 23. CAD Visualization

Generate diagrams showing:

### Straight neutral configuration

```text
HIP ========================>
```

### Moderate hip turn

```text
HIP ========
             =====
                  ===
                     ==
```

### Maximum safe curvature

Display angular-limit cones around every joint.

Also provide:

- exploded vertebra;
- ball cross-section;
- socket cross-section;
- center cord path;
- joint angle visualization;
- complete side view;
- complete top view;
- performer-scale reference.

---

# 24. Physics Output

Record at each timestep:

```text
time
pelvis_position
pelvis_orientation

each_joint_pitch
each_joint_yaw
each_joint_roll

tip_position
tip_velocity
tip_acceleration

cord_tension
```

Calculate:

```text
peak_tip_velocity
peak_tip_acceleration
maximum_tip_lag
maximum_tip_overshoot
maximum_joint_angle
settling_time
oscillation_count
```

Export results as CSV.

Generate plots for:

```text
hip yaw vs time
tip yaw vs time
tip displacement vs time
joint yaw vs time
```

The last graph should show whether motion actually propagates sequentially through the vertebrae.

---

# 25. Parameter Optimization

Concentrate primarily on:

```text
JOINT COUNT
JOINT FRICTION
CORD PRELOAD
MASS TAPER
JOINT ANGLE PROGRESSION
COM OFFSET
```

Do not optimize primarily for anatomical realism.

Optimize for:

> **Visually convincing passive practical-effects movement generated by an actor inside a bipedal creature suit.**

---

# 26. Desired Character of Motion

The target is intentionally somewhat theatrical.

It should feel:

```text
HEAVY AT ROOT
LOOSE AT TIP
SLIGHTLY LAGGY
ORGANIC
PHYSICALLY REACTIVE
```

It should NOT feel:

```text
ROBOTIC
PRECISE
SERVO-DRIVEN
SNAKE-LIKE
WHIP-LIKE DURING NORMAL WALKING
```

The mechanism should exploit inertia rather than fight it.

---

# 27. Critical Design Comparison

The simulation must compare at least these four configurations:

```text
A.
ball joints
centered COM
friction only

B.
ball joints
centered COM
friction + central cord preload

C.
ball joints
offset COM
friction + central cord preload

D.
ball joints
offset COM
friction + central cord preload
progressively increasing joint freedom toward tip
```

Use identical hip-motion tests for all four.

Do not simply declare a winner.

Generate comparable quantitative results and animations so a human can evaluate which motion looks most convincing.

---

# 28. Initial Reference Configuration

Start physics development with:

```text
Total length:
1400 mm

Mechanical articulated length:
1200 mm

Flexible foam tip:
200 mm

Joint count:
8

Root diameter:
190 mm

Last mechanical diameter:
70 mm

Cord:
6 mm

Taper exponent:
1.3

Joint limits:
8°, 10°, 12°, 15°,
18°, 20°, 24°, 28°

Approximate moving masses:
450, 400, 330, 270,
210, 160, 110, 70 g

Foam tip:
75 g
```

Treat these only as the initial experimental configuration.

---

# 29. First Development Milestone

Do NOT begin by perfecting cosmetic exterior geometry.

First produce a simplified physics representation consisting of:

```text
HIP BLOCK
    |
 [V1]
    O
 [V2]
    O
 [V3]
    O
 [V4]
    O
 [V5]
    O
 [V6]
    O
 [V7]
    O
 [V8]
    |
 FOAM TIP
```

Run the 30° hip-snap simulation.

Generate an animation and plots.

Once believable passive follow-through is demonstrated, generate the detailed ball/socket geometry in OpenSCAD and FreeCAD.

The first question to answer is not:

"Does this look like a dinosaur skeleton?"

It is:

**"When a human performer turns their hips, does this mechanism produce the exaggerated but physically believable secondary tail movement associated with traditional practical creature suits?"**

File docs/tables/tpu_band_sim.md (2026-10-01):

# Barney tail: TPU straps vs extension springs (as built, MuJoCo)

Generated by experiments/tpu_band_sim.py from the current straps.json. Straps are linearised at rest (T0 and k from cad/tpu_bands.py) or with the secant rate to the stop. Seat friction: felt liner mu 0.25, TPU liner mu 0.45, bare PETG mu 0.12 (tailsim FRICTION_LEVELS). The ±30 % rows model a material stiffer or softer than assumed after the rest pose is re-trimmed. TPU hysteresis (extra damping) is not modelled.

| case | snap lag | snap overshoot | swings | settle | 45° turn overshoot | walk tip/hip | rest clearance | crouch clearance | jump floor force | peak belt moment |
|---|---|---|---|---|---|---|---|---|---|---|
| springs, felt seat liner | 34° | 9° | 1 | 1.25 s | 31° | 1.95 | 52 cm | 47 cm | 0 N | 14.2 N·m |
| 95A straps, felt seat liner | 34° | 9° | 1 | 1.25 s | 32° | 1.95 | 52 cm | 47 cm | 0 N | 21.6 N·m |
| 95A straps (secant rate to the stop), felt | 35° | 1° | 1 | 1.31 s | 25° | 1.84 | 52 cm | 47 cm | 0 N | 14.0 N·m |
| 95A straps, TPU seat liner | 29° | 11° | 1 | 0.76 s | 25° | 1.94 | 52 cm | 47 cm | 0 N | 13.2 N·m |
| 95A straps, bare PETG seat + TPU cap cushion | 40° | 24° | 1 | 3.61 s | 53° | 2.48 | 52 cm | 47 cm | 0 N | 41.2 N·m |
| 95A straps k-30 %, felt | 35° | 2° | 1 | 1.51 s | 25° | 1.85 | 52 cm | 47 cm | 0 N | 14.3 N·m |
| 95A straps k+30 %, felt | 33° | 15° | 1 | 1.19 s | 37° | 2.02 | 52 cm | 48 cm | 0 N | 39.6 N·m |

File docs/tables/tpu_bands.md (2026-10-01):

# TPU strap schedule: Barney tail (replaces the 18 extension springs)

Generated by `cad/tpu_bands.py` (NOMINAL material curves (run the coupon test and --calib)), 0.4 mm nozzle, 0.2 mm layers. STLs in `cad/stl/barney_tpu_bands/`.
Print 24 straps in TPU 95A. One-file print: `plate_all_straps.stl`
(every strap, dorsal pairs included); spares 10 % tighter: `plate_tight10_spares.stl`.
The label is debossed on a small tab at the **fin / hip-arm (parent) end**: "3D" = joint 3 dorsal (pair, one each
side of the ear); "3L-T" / "3R-B" = joint 3 left / right lateral, strap on the **top** (dorsal) / **bottom**
(ventral) face of the ear and fin. A trailing "+" marks a tight spare.

Lengths are pin-centre to pin-centre (mm). Forces are for the whole spring position (both straps of a pair);
the spring targets are in brackets. "Break-in" is the pin-to-pin length to stretch each strap to, 10 times,
before installing.

| spring | tab label | file | straps | printed length | installed span | gauge w × t | spacer child / parent | T0 at rest, N | k, N/mm | T at stop, N | rest strain | break-in | bolts child / parent |
|---|---|---|---|---|---|---|---|---|---|---|---|---|---|
| J1 left | **1L-T** | `tpu95a/band_J1L.stl` | 1, top (dorsal) face | 31.9 | 38.2 | 2.7 × 0.6 | 2.3 / 2.9 | 6.1 (6.1) | 1.21 (1.21) | 13 (16) | 15 % | 50 | M4×30 / M4×25 |
| J1 right | **1R-B** | `tpu95a/band_J1R.stl` | 1, bottom (ventral) face | 31.9 | 38.2 | 2.7 × 0.6 | 2.3 / 2.9 | 6.1 (6.1) | 1.21 (1.21) | 13 (16) | 15 % | 50 | M4×30 / M4×25 |
| J1 dorsal | **1D** | `tpu95a/band_J1D.stl` | pair, both faces | 30.6 | 38.2 | 10.8 × 0.8 | 2.6 / 3.2 | 96.1 (96.1) | 11.85 (5.90) | 158 (146) | 25 % | 50 | M4×30 / M4×30 |
| J2 left | **2L-B** | `tpu95a/band_J2L.stl` | 1, bottom (ventral) face | 41.1 | 48.7 | 4.1 × 0.6 | 2.8 / 5.1 | 7.5 (7.5) | 1.42 (1.42) | 17 (20) | 12 % | 61 | M4×30 / M4×25 |
| J2 right | **2R-B** | `tpu95a/band_J2R.stl` | 1, bottom (ventral) face | 41.1 | 48.7 | 4.1 × 0.6 | 2.8 / 5.1 | 7.5 (7.5) | 1.42 (1.42) | 17 (20) | 12 % | 61 | M4×30 / M4×25 |
| J2 dorsal | **2D** | `tpu95a/band_J2D.stl` | pair, both faces | 61.3 | 75.3 | 12.9 × 0.6 | 3.9 / 6.2 | 66.4 (66.4) | 5.47 (5.47) | 108 (120) | 18 % | 90 | M4×35 / M4×30 |
| J3 left | **3L-B** | `tpu95a/band_J3L.stl` | 1, bottom (ventral) face | 35.7 | 43.5 | 2.6 × 0.6 | 3.4 / 5.8 | 6.3 (6.3) | 0.97 (0.97) | 13 (17) | 17 % | 58 | M4×30 / M4×25 |
| J3 right | **3R-B** | `tpu95a/band_J3R.stl` | 1, bottom (ventral) face | 35.7 | 43.5 | 2.6 × 0.6 | 3.4 / 5.8 | 6.3 (6.3) | 0.97 (0.97) | 13 (17) | 17 % | 58 | M4×30 / M4×25 |
| J3 dorsal | **3D** | `tpu95a/band_J3D.stl` | pair, both faces | 49.1 | 62.4 | 6.9 × 0.6 | 3.9 / 6.4 | 40.6 (40.6) | 3.26 (3.26) | 67 (78) | 21 % | 79 | M4×35 / M4×30 |
| J4 left | **4L-T** | `tpu95a/band_J4L.stl` | 1, top (dorsal) face | 28.0 | 35.7 | 2.0 × 0.6 | 4.1 / 5.9 | 6.5 (6.5) | 0.80 (0.80) | 12 (17) | 25 % | 54 | M4×30 / M4×25 |
| J4 right | **4R-T** | `tpu95a/band_J4R.stl` | 1, top (dorsal) face | 28.0 | 35.7 | 2.0 × 0.6 | 4.1 / 5.9 | 6.5 (6.5) | 0.80 (0.80) | 12 (17) | 25 % | 54 | M4×30 / M4×25 |
| J4 dorsal | **4D** | `tpu95a/band_J4D.stl` | pair, both faces | 25.9 | 32.9 | 4.4 × 0.6 | 4.1 / 5.9 | 29.3 (29.3) | 3.91 (1.56) | 55 (50) | 25 % | 50 | M4×35 / M4×30 |
| J5 left | **5L-T** | `tpu95a/band_J5L.stl` | 1, top (dorsal) face | 38.5 | 47.1 | 5.1 × 0.6 | 4.8 / 7.2 | 12.5 (12.5) | 1.73 (1.73) | 26 (33) | 17 % | 63 | M4×30 / M4×25 |
| J5 right | **5R-T** | `tpu95a/band_J5R.stl` | 1, top (dorsal) face | 38.5 | 47.1 | 5.1 × 0.6 | 4.8 / 7.2 | 12.5 (12.5) | 1.73 (1.73) | 26 (33) | 17 % | 63 | M4×30 / M4×25 |
| J5 dorsal | **5D** | `tpu95a/band_J5D.stl` | pair, both faces | 22.9 | 29.0 | 5.0 × 0.6 | 4.8 / 7.2 | 33.1 (33.1) | 5.19 (3.15) | 58 (60) | 25 % | 41 | M4×35 / M4×35 |
| J6 left | **6L-T** | `tpu95a/band_J6L.stl` | 1, top (dorsal) face | 36.8 | 46.0 | 2.8 × 0.6 | 5.5 / 8.7 | 7.8 (7.8) | 0.92 (0.92) | 15 (21) | 20 % | 65 | M4×30 / M4×25 |
| J6 right | **6R-T** | `tpu95a/band_J6R.stl` | 1, top (dorsal) face | 36.8 | 46.0 | 2.8 × 0.6 | 5.5 / 8.7 | 7.8 (7.8) | 0.92 (0.92) | 15 (21) | 20 % | 65 | M4×30 / M4×25 |
| J6 dorsal | **6D** | `tpu95a/band_J6D.stl` | pair, both faces | 28.6 | 34.1 | 2.1 × 0.6 | 5.5 / 8.7 | 9.2 (9.2) | 2.08 (2.08) | 23 (35) | 15 % | 50 | M4×40 / M4×35 |

Bolts (M4 socket head + washer each side + nylock): 12 × M4×25, 17 × M4×30, 6 × M4×35, 1 × M4×40.

Material curves used:
- `tpu95a`: tanh, E0 22.0 MPa, s1 6.8, E2 4.0, set after break-in 8 %, max rest strain 25 %
- `tpu65a`: neo, E0 4.5 MPa, set after break-in 3 %, max rest strain 80 %

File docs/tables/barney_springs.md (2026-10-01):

# Spring schedule: Barney tail (6 joints)

From the physics spring design of the recommended tail. Choose extension springs of the listed rate whose force at the installed length is T0 (a short cord loop on a hook trims T0). Where the stop tension exceeds ~120 N use two springs in parallel (each with half k and T0).

| joint | spring | k (N/mm) | T0 at rest (N) | T at stop (N) | arm (mm) | installed length (mm) | max coil OD (mm) | count |
|---|---|---|---|---|---|---|---|---|
| J1 | left | 1.21 | 6.1 | 16.2 | 60.0 | 38.2 | 15.2 | 1 |
| J1 | right | 1.21 | 6.1 | 16.2 | 60.0 | 38.2 | 15.2 | 1 |
| J1 | dorsal | 5.90 | 96.1 | 145.5 | 60.0 | 38.2 | 15.2 | 2 in parallel |
| J2 | left | 1.42 | 7.5 | 20.1 | 46.1 | 48.7 | 13.8 | 1 |
| J2 | right | 1.42 | 7.5 | 20.1 | 46.1 | 48.7 | 13.8 | 1 |
| J2 | dorsal | 5.47 | 66.4 | 120.1 | 51.1 | 75.3 | 13.8 | 2 in parallel |
| J3 | left | 0.97 | 6.3 | 16.8 | 44.1 | 43.5 | 12.3 | 1 |
| J3 | right | 0.97 | 6.3 | 16.8 | 44.1 | 43.5 | 12.3 | 1 |
| J3 | dorsal | 3.26 | 40.6 | 78.3 | 47.3 | 62.4 | 12.3 | 1 |
| J4 | left | 0.80 | 6.5 | 17.4 | 43.1 | 35.7 | 10.9 | 1 |
| J4 | right | 0.80 | 6.5 | 17.4 | 43.1 | 35.7 | 10.9 | 1 |
| J4 | dorsal | 1.56 | 29.3 | 50.2 | 42.7 | 32.9 | 10.9 | 1 |
| J5 | left | 1.73 | 12.5 | 33.3 | 31.3 | 47.1 | 9.4 | 1 |
| J5 | right | 1.73 | 12.5 | 33.3 | 31.3 | 47.1 | 9.4 | 1 |
| J5 | dorsal | 3.15 | 33.1 | 60.3 | 22.4 | 29.0 | 9.4 | 1 |
| J6 | left | 0.92 | 7.8 | 20.9 | 31.2 | 46.0 | 8.0 | 1 |
| J6 | right | 0.92 | 7.8 | 20.9 | 31.2 | 46.0 | 8.0 | 1 |
| J6 | dorsal | 2.08 | 9.2 | 35.4 | 27.7 | 34.1 | 8.0 | 1 |

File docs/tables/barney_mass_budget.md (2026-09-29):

# Moving-mass budget: Barney tail (grams)

Printed masses from the exported STLs (PETG, 3 perimeters, 20 % infill).

| segment | printed | hardware | springs | foam | skin | total | simulated |
|---|---|---|---|---|---|---|---|
| V1 | 360 | 33 | 20 | 40 | 22 | **475** | 469 |
| V2 | 318 | 33 | 16 | 33 | 20 | **421** | 415 |
| V3 | 287 | 33 | 13 | 26 | 18 | **377** | 374 |
| V4 | 250 | 33 | 13 | 20 | 16 | **332** | 329 |
| V5 | 224 | 33 | 13 | 15 | 14 | **298** | 296 |
| V6 | 188 | 29 | 5 | 11 | 12 | **244** | 243 |

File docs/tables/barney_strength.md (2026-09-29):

# Strength check: Barney tail (all simulated motions incl. jump and bend-over)

Neck design moment = peak ball moment + peak lateral ball force x neck length; allowable 20 MPa. Cap ear = peak spring tension as an out-of-plane cantilever on the ear (16 mm on root caps, 12 mm elsewhere) vs PETG UTS 45 MPa.

| joint | neck design moment (N·m) | neck allowable (N·m) | neck SF | peak spring tension (N) | ear stress (MPa) | ear SF |
|---|---|---|---|---|---|---|
| J1 | 9.82 | 42.8 | 4.4 | 148 | 4.0 | 11.2 |
| J2 | 7.76 | 33.4 | 4.3 | 106 | 2.6 | 17.0 |
| J3 | 6.58 | 23.9 | 3.6 | 78 | 1.8 | 24.5 |
| J4 | 4.45 | 20.5 | 4.6 | 51 | 0.9 | 47.7 |
| J5 | 6.21 | 20.5 | 3.3 | 51 | 0.6 | 80.7 |
| J6 | 4.69 | 20.5 | 4.4 | 39 | 0.2 | 195.5 |

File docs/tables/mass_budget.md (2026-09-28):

# Moving-mass budget per segment (grams)

Printed masses from the exported STLs (3 perimeters of 1.3 mm solid, 20 % core infill, PETG 1.27 g/cm³).

| segment | printed | hardware | springs | foam | skin | total | README target |
|---|---|---|---|---|---|---|---|
| V1 | 368 | 33 | 31 | 48 | 27 | **507** | 450 |
| V2 | 317 | 33 | 27 | 38 | 24 | **438** | 400 |
| V3 | 269 | 33 | 23 | 29 | 21 | **375** | 330 |
| V4 | 229 | 32 | 20 | 21 | 18 | **321** | 270 |
| V5 | 179 | 32 | 18 | 15 | 16 | **260** | 210 |
| V6 | 166 | 32 | 17 | 10 | 13 | **239** | 160 |
| V7 | 154 | 32 | 16 | 7 | 11 | **220** | 110 |
| V8 | 145 | 29 | 7 | 4 | 10 | **195** | 70 |

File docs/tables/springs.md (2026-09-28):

# Spring schedule (reference design)

Generated by experiments/make_tables.py from the physics spring design.
Buy extension springs with the listed rate whose force at the installed length equals T0;
parallel pairs are fine (halve k and T0 each). Adjust T0 with a short cord loop on the hook.

| joint | spring | rate k (N/mm) | tension at rest T0 (N) | tension at stop (N) | moment arm (mm) | installed length (mm) | max coil OD (mm) |
|---|---|---|---|---|---|---|---|
| J1 | left | 3.16 | 15.9 | 42.4 | 60.0 | 39.0 | 10.0 |
| J1 | right | 3.16 | 15.9 | 42.4 | 60.0 | 39.0 | 10.0 |
| J1 | dorsal | 12.14 | 145.4 | 216.5 | 60.0 | 39.0 | 10.0 |
| J2 | left | 3.05 | 17.0 | 45.3 | 53.1 | 37.0 | 10.0 |
| J2 | right | 3.05 | 17.0 | 45.3 | 53.1 | 37.0 | 10.0 |
| J2 | dorsal | 9.86 | 115.0 | 179.0 | 53.1 | 37.0 | 10.0 |
| J3 | left | 2.82 | 16.5 | 44.1 | 46.7 | 34.5 | 10.0 |
| J3 | right | 2.82 | 16.5 | 44.1 | 46.7 | 34.5 | 10.0 |
| J3 | dorsal | 7.73 | 88.2 | 141.1 | 46.7 | 34.5 | 10.0 |
| J4 | left | 2.61 | 16.7 | 44.5 | 40.7 | 32.4 | 10.0 |
| J4 | right | 2.61 | 16.7 | 44.5 | 40.7 | 32.4 | 10.0 |
| J4 | dorsal | 5.76 | 65.1 | 108.0 | 40.7 | 32.4 | 10.0 |
| J5 | left | 2.46 | 16.3 | 43.5 | 35.3 | 31.6 | 8.8 |
| J5 | right | 2.46 | 16.3 | 43.5 | 35.3 | 31.6 | 8.8 |
| J5 | dorsal | 4.91 | 45.6 | 83.6 | 35.3 | 31.6 | 8.8 |
| J6 | left | 2.72 | 17.4 | 46.4 | 30.6 | 32.7 | 7.5 |
| J6 | right | 2.72 | 17.4 | 46.4 | 30.6 | 32.7 | 7.5 |
| J6 | dorsal | 5.43 | 29.6 | 70.1 | 30.6 | 32.7 | 7.5 |
| J7 | left | 2.76 | 19.5 | 51.9 | 28.1 | 35.0 | 6.4 |
| J7 | right | 2.76 | 19.5 | 51.9 | 28.1 | 35.0 | 6.4 |
| J7 | dorsal | 5.52 | 16.3 | 61.7 | 28.1 | 35.0 | 6.4 |
| J8 | left | 2.28 | 18.5 | 49.4 | 27.7 | 37.1 | 5.6 |
| J8 | right | 2.28 | 18.5 | 49.4 | 27.7 | 37.1 | 5.6 |
| J8 | dorsal | 4.56 | 7.0 | 50.2 | 27.7 | 37.1 | 5.6 |

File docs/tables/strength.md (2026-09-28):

# Strength check (as-built tail: CAD masses, all standard motion tests)

Neck design moment = peak moment carried through the ball (friction + stop) + peak *lateral* ball force x neck length (peak moment and peak force are combined even if they occur at different instants, which is conservative; the axial seat compression from the spring preload does not bend the neck). Allowable = 20 MPa on the hollow neck section (layers run along the neck in the clamshell ball halves). Cap ear: dorsal/lateral spring peak tension as an out-of-plane cantilever load on the 10 mm ear, compared with PETG UTS 45 MPa.

| joint | peak ball moment (N·m) | peak ball force total / lateral (N) | neck design moment (N·m) | neck allowable (N·m) | neck SF | peak spring tension (N) | ear stress (MPa) | ear SF vs UTS |
|---|---|---|---|---|---|---|---|---|
| J1 | 4.39 | 281 / 59 | 6.38 | 42.8 | 6.7 | 218 | 15.1 | 3.0 |
| J2 | 2.66 | 248 / 51 | 4.29 | 31.2 | 7.3 | 181 | 11.4 | 4.0 |
| J3 | 2.05 | 214 / 46 | 3.40 | 20.9 | 6.1 | 146 | 8.4 | 5.3 |
| J4 | 1.38 | 185 / 36 | 2.38 | 13.5 | 5.7 | 113 | 6.0 | 7.5 |
| J5 | 0.98 | 155 / 33 | 1.86 | 9.2 | 4.9 | 82 | 3.7 | 12.3 |
| J6 | 0.76 | 132 / 29 | 1.56 | 9.2 | 5.9 | 65 | 1.6 | 27.5 |
| J7 | 0.60 | 109 / 19 | 1.17 | 9.2 | 7.8 | 54 | 0.8 | 55.5 |
| J8 | 0.39 | 75 / 10 | 0.72 | 9.2 | 12.7 | 36 | 0.5 | 92.3 |

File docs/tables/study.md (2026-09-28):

# Configuration study (identical hip inputs)

Hip snap = 30° in 0.35 s; turn = 45° in 0.5 s; walk = ±5° yaw, ±3° roll, ±20 mm bob at 1.5 and 2.0 steps/s. Angles in degrees, times in s, velocity in m/s, heights in m. Lowest mode: smallest small-motion frequency about the rest pose (negative = statically unstable). Score: penalty vs the README target bands (lower = closer; see tailsim/metrics.py).

| configuration | snap lag | snap overshoot | oscillations | settle | residual | turn overshoot | walk whip 1.5/2.0 | peak tip v | max roll | crouch min tip z | crouch floor N | lowest mode Hz | score |
|---|---|---|---|---|---|---|---|---|---|---|---|---|---|
| A friction only | 41.1 | 14.0 | 1 | 2.15 | 0.3 | 36.5 | 1.86 / 1.57 | 4.73 | 7.9 | 0.41 | 0.0 | 0.346 | 39.2 |
| B + cord preload | 40.0 | 9.7 | 1 | 1.70 | 0.2 | 27.5 | 1.73 / 1.40 | 3.93 | 7.5 | 0.41 | 0.0 | 0.303 | 10.1 |
| C + offset COM | 39.7 | 10.7 | 1 | 1.61 | 0.1 | 29.4 | 1.77 / 1.41 | 3.94 | 7.5 | 0.41 | 0.0 | 0.336 | 14.5 |
| D + progressive limits | 39.6 | 2.7 | 1 | 0.91 | 0.1 | 23.3 | 1.64 / 1.36 | 3.01 | 7.3 | 0.41 | 0.0 | 0.232 | 3.6 |
| reference (= D, tuned) | 39.6 | 2.7 | 1 | 0.91 | 0.1 | 23.3 | 1.64 / 1.36 | 3.01 | 7.3 | 0.41 | 0.0 | 0.232 | 3.6 |
| reference, CAD masses | 38.6 | 10.3 | 1 | 1.91 | 0.0 | 28.7 | 1.61 / 1.27 | 3.13 | 7.2 | 0.41 | 0.0 | 0.320 | 12.7 |
| naive: no springs | 43.4 | 0.0 | 1 | 4.19 | 33.1 | 37.6 | 0.45 / 0.45 | 2.10 | 7.8 | 0.01 | 11.4 | -5.948 | 15087.7 |
| D, roll unrestricted | 39.6 | 0.0 | 1 | 2.87 | 1.0 | 2.2 | 1.64 / 1.36 | 2.88 | 9.7 | 0.41 | 0.0 | 0.232 | 5.6 |
| com_0mm | 39.6 | 1.4 | 0 | 0.41 | 0.5 | 20.9 | 1.61 / 1.36 | 2.95 | 7.3 | 0.41 | 0.0 | 0.181 | 5.0 |
| com_15mm | 39.6 | 2.7 | 1 | 0.91 | 0.1 | 23.3 | 1.64 / 1.36 | 3.01 | 7.3 | 0.41 | 0.0 | 0.232 | 3.6 |
| com_30mm | 39.3 | 3.8 | 1 | 1.01 | 0.0 | 25.5 | 1.69 / 1.37 | 3.06 | 7.3 | 0.41 | 0.0 | 0.269 | 6.3 |
| com_50mm | 38.9 | 4.9 | 1 | 1.04 | 0.0 | 28.3 | 1.78 / 1.40 | 3.10 | 7.3 | 0.40 | 0.0 | 0.307 | 11.7 |
| preload_5N | 40.4 | 0.8 | 1 | 0.44 | 0.9 | 22.9 | 1.59 / 1.32 | 3.04 | 7.3 | 0.41 | 0.0 | 0.167 | 5.5 |
| preload_10N | 39.6 | 2.7 | 1 | 0.91 | 0.1 | 23.3 | 1.64 / 1.36 | 3.01 | 7.3 | 0.41 | 0.0 | 0.232 | 3.6 |
| preload_20N | 38.3 | 5.8 | 1 | 1.20 | 0.0 | 23.6 | 1.75 / 1.44 | 3.24 | 7.2 | 0.41 | 0.0 | 0.314 | 3.4 |
| preload_40N | 36.5 | 10.6 | 1 | 1.24 | 0.0 | 25.6 | 1.98 / 1.59 | 3.52 | 7.1 | 0.41 | 0.0 | 0.416 | 6.4 |
| friction_VERY_LOW | 48.0 | 45.9 | 2 | 3.24 | 0.1 | 69.4 | 2.15 / 2.17 | 7.11 | 8.9 | 0.41 | 0.0 | 0.358 | 582.5 |
| friction_LOW | 48.0 | 16.0 | 1 | 3.74 | 8.8 | 55.1 | 1.68 / 1.45 | 5.16 | 7.9 | 0.40 | 0.0 | 0.152 | 175.3 |
| friction_MEDIUM | 39.6 | 2.7 | 1 | 0.91 | 0.1 | 23.3 | 1.64 / 1.36 | 3.01 | 7.3 | 0.41 | 0.0 | 0.232 | 3.6 |
| friction_HIGH | 31.1 | 22.6 | 2 | 1.78 | 0.0 | 34.4 | 3.07 / 2.73 | 4.93 | 4.5 | 0.41 | 0.0 | 0.743 | 62.1 |
| joints_6 | 39.5 | 12.1 | 1 | 2.00 | 0.1 | 35.4 | 1.71 / 1.53 | 4.37 | 7.2 | 0.44 | 0.0 | 0.420 | 33.7 |
| joints_10 | 39.5 | 4.2 | 1 | 1.25 | 0.2 | 22.6 | 1.61 / 1.31 | 2.91 | 7.2 | 0.37 | 0.0 | 0.207 | 2.4 |
| joints_12 | 39.9 | 7.0 | 1 | 1.93 | 0.2 | 25.9 | 1.63 / 1.32 | 2.99 | 7.2 | 0.33 | 0.0 | 0.234 | 6.9 |
| mass_uniform | 37.8 | 14.0 | 1 | 2.44 | 0.0 | 32.0 | 1.30 / 1.01 | 2.63 | 7.3 | 0.41 | 0.0 | 0.271 | 22.6 |
| limits_uniform_all | 39.7 | 10.7 | 1 | 1.61 | 0.1 | 29.4 | 1.77 / 1.41 | 3.94 | 7.5 | 0.41 | 0.0 | 0.336 | 14.5 |

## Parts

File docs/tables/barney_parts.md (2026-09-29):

# Print list: Barney tail

All STLs in `cad/stl/barney/`, already in print orientation. One of each file; every part fits a 200 mm cube.

| part | bounding box (mm) | est. mass (g) |
|---|---|---|
| ball_1_left | 65x56x28 | 33 |
| ball_1_right | 65x56x28 | 33 |
| ball_2_left | 77x70x26 | 30 |
| ball_2_right | 77x70x26 | 30 |
| ball_3_left | 69x60x23 | 24 |
| ball_3_right | 69x60x23 | 24 |
| ball_4_left | 56x45x22 | 20 |
| ball_4_right | 56x45x22 | 20 |
| ball_5_left | 69x64x22 | 22 |
| ball_5_right | 69x64x22 | 22 |
| ball_6_left | 68x58x22 | 21 |
| ball_6_right | 68x58x22 | 21 |
| body_1 | 150x150x76 | 241 |
| body_2 | 136x136x81 | 222 |
| body_3 | 122x122x88 | 206 |
| body_4 | 108x108x78 | 172 |
| body_5 | 94x94x78 | 151 |
| body_6 | 80x80x100 | 147 |
| cap_1_a | 69x78x22 | 27 |
| cap_1_b | 99x78x22 | 32 |
| cap_2_a | 65x72x20 | 22 |
| cap_2_b | 91x72x20 | 27 |
| cap_3_a | 61x66x17 | 18 |
| cap_3_b | 84x66x17 | 22 |
| cap_4_a | 59x59x16 | 16 |
| cap_4_b | 78x59x16 | 19 |
| cap_5_a | 59x54x16 | 14 |
| cap_5_b | 72x54x16 | 16 |
| cap_6_a | 59x50x16 | 12 |
| cap_6_b | 68x50x16 | 14 |
| hip_mount | 174x190x48 | 228 |
| tip_adapter | 30x30x70 | 14 |

**Total printed PETG: 1.92 kg** (32 files).

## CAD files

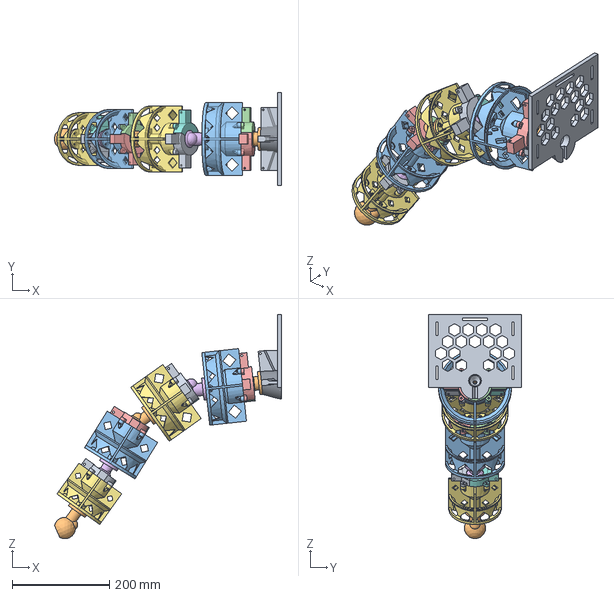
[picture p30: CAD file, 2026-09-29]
cad/freecad/output/test_section_4joint_barney.step
466.2 x 190.0 x 460.9 mm

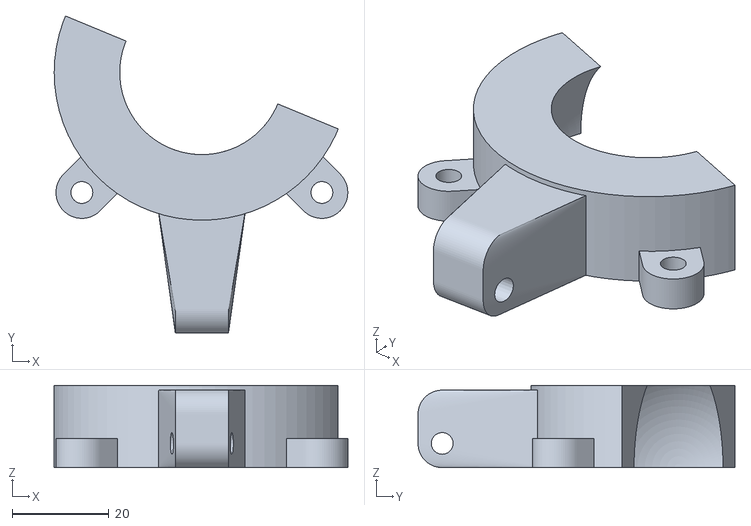
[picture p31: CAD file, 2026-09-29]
cad/stl/barney/cap_3_a.stl
60.6 x 65.5 x 17.0

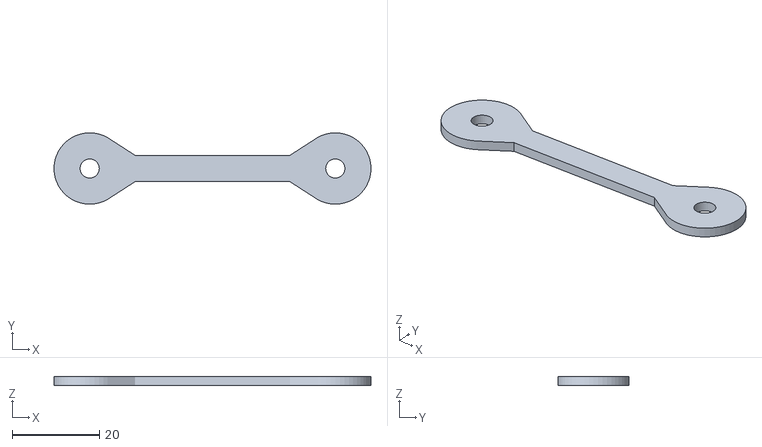
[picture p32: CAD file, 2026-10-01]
cad/stl/barney_tpu_bands/calibration/coupon_tpu65a.stl
72.8 x 16.4 x 2.00

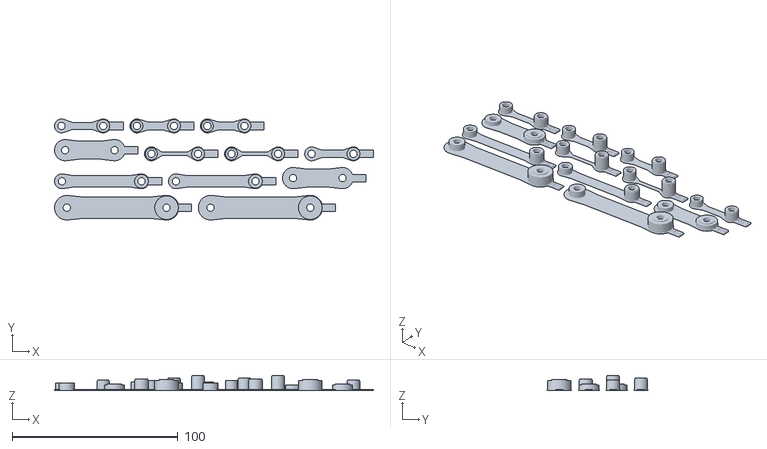
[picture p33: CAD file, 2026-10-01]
cad/stl/barney_tpu_bands/plate_tight10_spares.stl
192.3 x 60.9 x 9.30

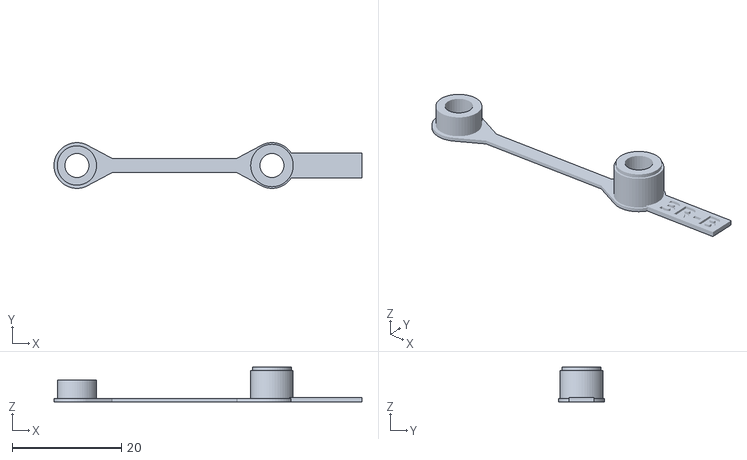
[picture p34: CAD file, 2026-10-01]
cad/stl/barney_tpu_bands/tpu95a/band_J3R.stl
56.4 x 8.40 x 6.40

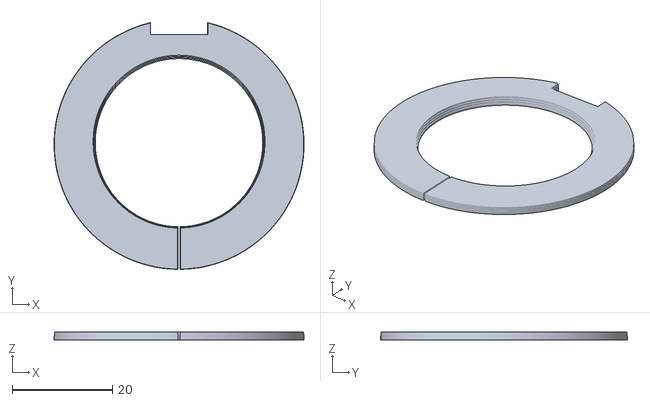
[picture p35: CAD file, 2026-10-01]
cad/stl/barney_tpu_liners/mouth_rings/mouth_ring_J4.stl
49.8 x 49.1 x 1.60

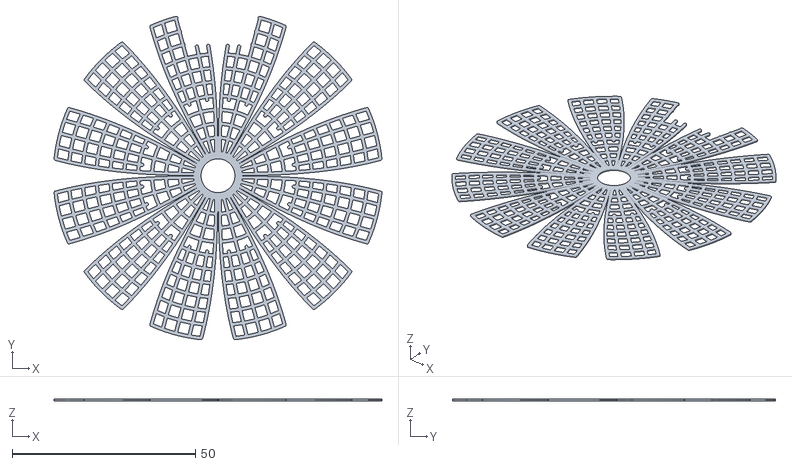
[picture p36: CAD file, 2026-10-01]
cad/stl/barney_tpu_liners/seat_liners/seat_liner_J1.stl
89.5 x 88.3 x 0.5

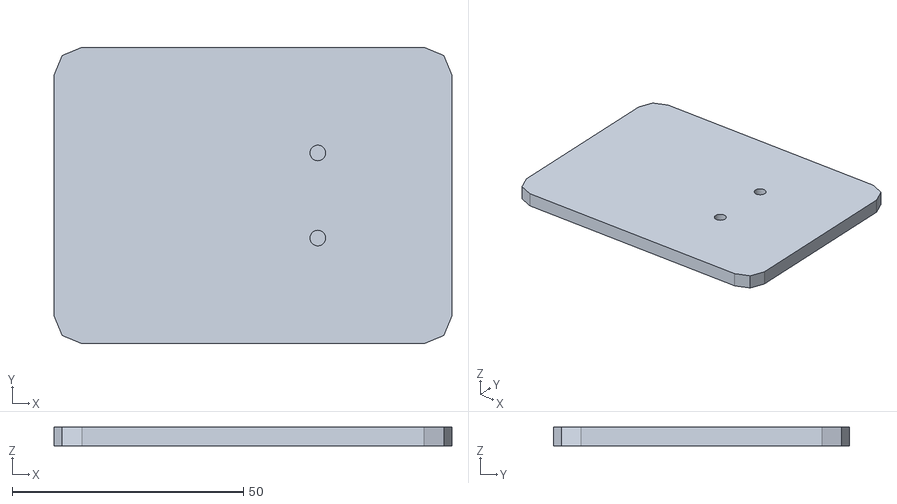
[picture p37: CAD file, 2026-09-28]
cad/stl/figurine_1to8_resin/22_display_base.stl
86.0 x 64.0 x 4.00

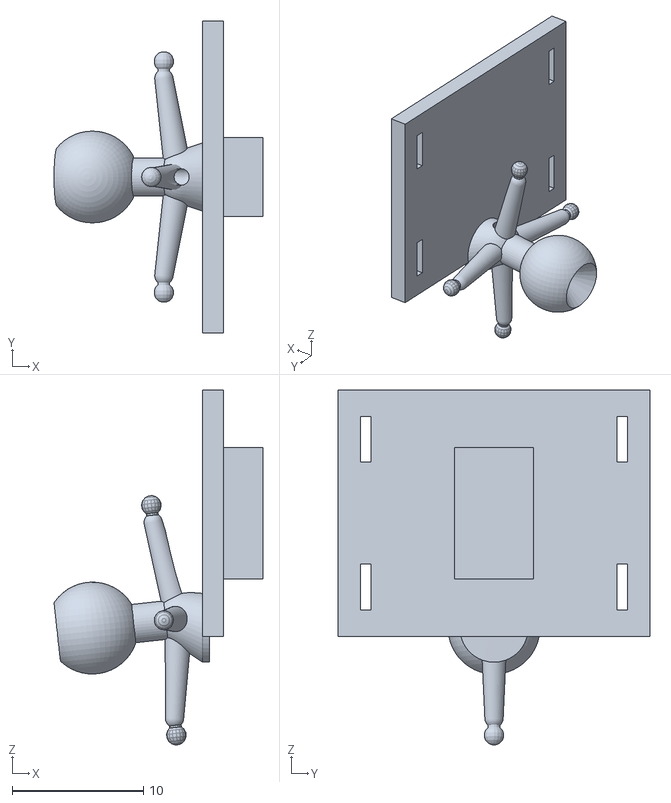
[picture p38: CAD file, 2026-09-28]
cad/stl/replica_1to8_resin/01_hip_mount_plate.stl
15.9 x 23.8 x 27.0

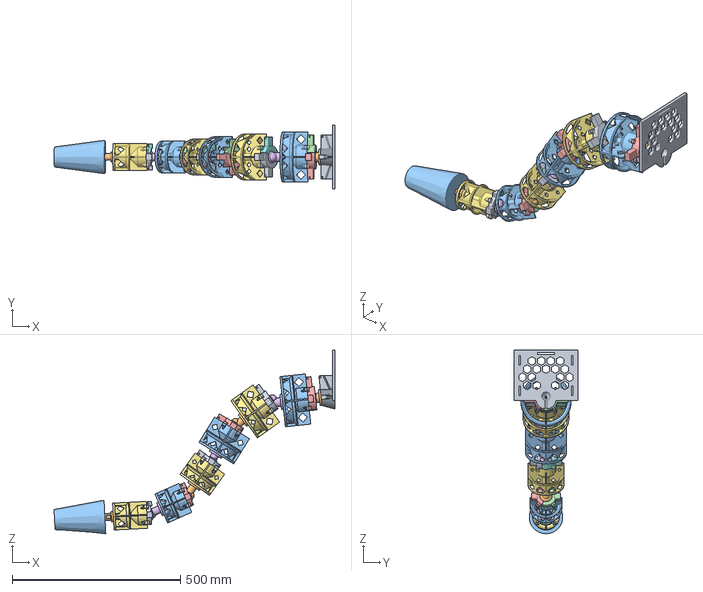
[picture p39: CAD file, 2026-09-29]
cad/freecad/output/suit_tail_barney.step
835.3 x 190.0 x 545.8 mm

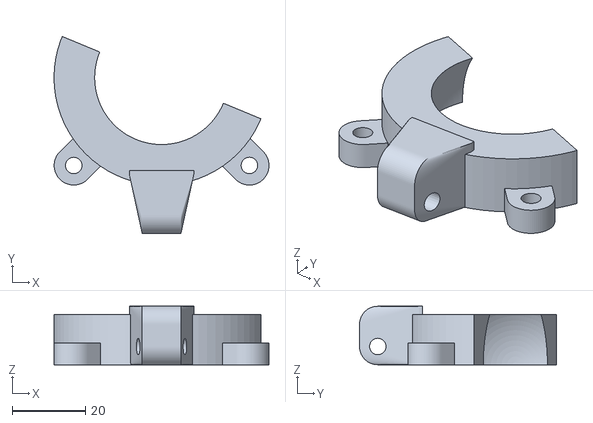
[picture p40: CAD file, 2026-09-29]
cad/stl/barney/cap_5_a.stl
58.8 x 53.8 x 16.0

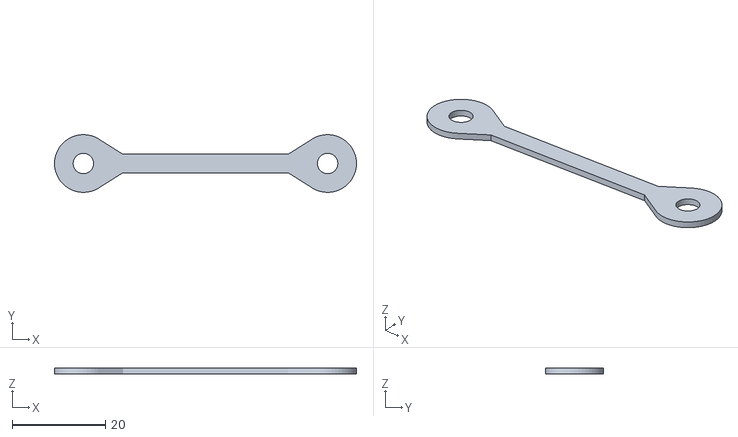
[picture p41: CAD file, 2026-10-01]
cad/stl/barney_tpu_bands/calibration/coupon_tpu95a.stl
64.8 x 12.4 x 1.20

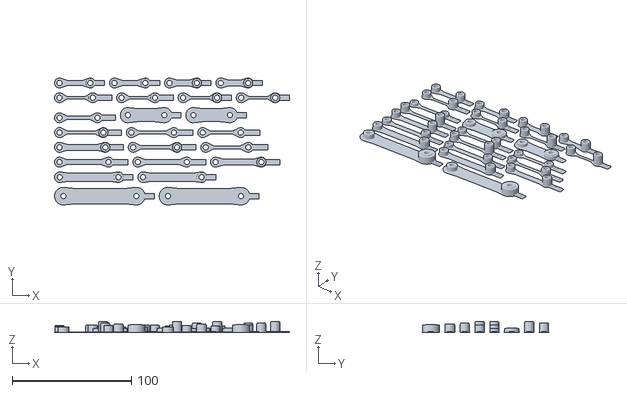
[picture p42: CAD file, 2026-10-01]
cad/stl/barney_tpu_bands/plate_all_straps.stl
197.3 x 106.6 x 9.30

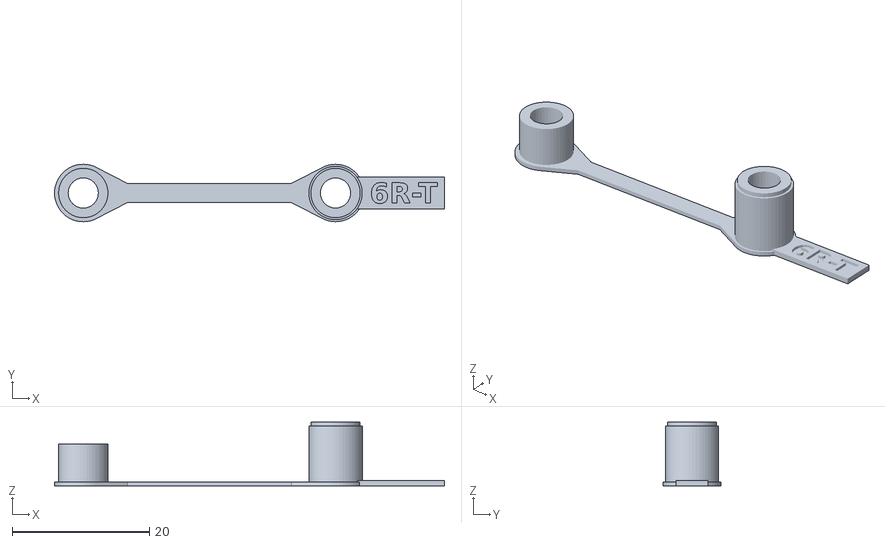
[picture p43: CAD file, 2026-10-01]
cad/stl/barney_tpu_bands/tpu95a/band_J6R.stl
56.9 x 8.40 x 9.30

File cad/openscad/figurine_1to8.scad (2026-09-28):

// 1:8 scale low-poly display figurine: skinny 5 ft 8 in (1727 mm) male body with a protogen head
// ----------------------------------------------------------------------------------------
// Resin (Anycubic Photon Mono 5s) companion to the 1:8 tail kit (mini_kit.scad). A raised
// "cyber spine" rail on the back carries a T-channel: the kit's lumbar-belt plate
// (01_hip_mount_plate) slides down into it from the top, its stand tab running in the centre
// groove and its edges captured behind two lips. A pin pushed through a pair of lip holes
// stops the plate at that level, so the tail can be tried at different heights.
//
// Frame: the pelvis frame of the tail CAD, scaled 1:8. Origin = pelvis centre at 0.55 H above
// the floor, +X forward (the tail hangs toward -X), +Z up, +Y the figure's left.
// At DZ = 0 the plate sits exactly where the full-size design puts it (plate_z above the
// pelvis centre, front face harness_plate_offset behind it).
//
// FIG = "body" | "head" | "base" | "pin" | "assembly" | "none"
include <mini_kit.scad>
MINI = "none";                 // silence the kit dispatcher
FIG = "assembly";

H   = 1727 * S;                // 215.9 mm figure height (to the crown of a human head)
fz  = -0.55 * 1727 * S;        // floor, -118.7 (same floor as the kit's display stand)
LP = 8;                        // low-poly facet count for all organic shapes
$fn = 8;                       // = LP (a literal: $fn is first assigned in mini_kit.scad, before LP exists)

// ---- plate / channel geometry (all from the kit's hip plate) -------------------------------
pt      = max(hip_plate_t * S, 1.6);           // 1.6 plate thickness
pfx     = -harness_plate_offset * S;           // -15.0 plate front (body) face
pw      = hip_plate_w * S;                     // 23.75
ph      = hip_plate_h * S;                     // 18.75
pz      = plate_z * S;                         // 5.0 plate centre at the design level
c_x     = 0.20;                                // channel clearance behind the plate (x)
c_y     = 0.20;                                // channel clearance at each plate edge (y)
mouth   = 10.3;                                // half-width of the opening between the lips
lip_t   = 1.5;                                 // lip thickness (x)
rail_hw = 14.6;                                // rail half-width
rail_front = -8.0;                             // rail is fused into the body forward of this
tab_hw  = 3.0 + 0.25;                          // stand tab: 6 wide ...
tab_d   = 3.0 + 0.4;                           // ... 3 deep
DZ_MIN  = -16;                                 // lowest level (plate sits on the channel floor)
LEVELS  = [for (d = [-12 : 4 : 36]) d];        // pin rows: plate raised by d mm (1:8) from design
pin_r   = 0.5;  pin_hole_r = 0.6;  pin_y = 11.25;
ch_bot  = pz - ph / 2 + DZ_MIN - 0.1;          // -20.5
rail_bot = ch_bot - 1.6;
rail_top = pz + ph / 2 + LEVELS[len(LEVELS) - 1] + 3.5;
lip_back = pfx - pt - c_x - lip_t;             // -18.3 outer face of the lips

// ---- primitives ---------------------------------------------------------------------------------
module ell(c, r, k = 0) translate(c) scale([max(r[0] - k, 0.2), max(r[1] - k, 0.2), max(r[2] - k, 0.2)]) sphere(r = 1);
module cap(a, b, ra, rb) hull() { translate(a) sphere(r = ra); translate(b) sphere(r = rb); }
module mir() { children(); mirror([0, 1, 0]) children(); }

// ---- body -------------------------------------------------------------------------------------------
// torso cross-sections: [centre, radii]; the union of consecutive hulls keeps the lumbar curve
TS = [
    [[-1.0, 0, -12], [11.0, 17.5, 5]],        // crotch / lower pelvis
    [[-1.5, 0,  -2], [12.0, 18.8, 6]],        // hips (greater trochanter)
    [[ 0.5, 0,  14], [10.6, 15.3, 5]],        // waist
    [[ 1.8, 0,  34], [12.6, 17.8, 8]],        // chest
    [[ 0.0, 0,  50], [10.0, 19.2, 6]],        // shoulder girdle
];
module torso(k = 0) {
    for (i = [0 : len(TS) - 2]) hull() { ell(TS[i][0], TS[i][1], k); ell(TS[i + 1][0], TS[i + 1][1], k); }
    mir() {
        ell([-5.5, 8, -9], [8, 8.5, 9], k);           // glutes
        ell([-5.5, 9, 42], [6.5, 7.5, 9], k);         // shoulder blades
    }
}

module arm() {
    Sh = [0, 20, 51]; E = [-1.5, 23.5, 17.5]; W = [1.0, 25.5, -13];
    ell([0, 19.5, 52], [5.5, 5.2, 6.2]);                      // deltoid
    hull() { translate(Sh) sphere(r = 4.2); ell([-0.5, 22.0, 36], [4.2, 4.1, 9]); translate(E) sphere(r = 3.2); }   // upper arm
    hull() { translate(E) sphere(r = 3.3); ell([-0.3, 24.2, 8], [3.7, 3.4, 7]); translate(W) sphere(r = 2.3); }     // forearm
    hull() {                                                    // hand, palm toward the thigh
        ell(W + [0.4, 0.2, -2.0], [3.3, 1.8, 2.5]);
        ell([2.0, 26.3, -25.5], [4.4, 1.8, 5.0]);
        ell([2.2, 26.5, -33.5], [2.8, 1.5, 3.2]);
    }
    cap([3.8, 25.2, -17], [5.6, 24.4, -24], 1.2, 1.0);        // thumb
}

module leg() {
    Hp = [0, 10, -4]; K = [0.8, 8.8, -57]; A = [-0.5, 8.3, -110.3];
    hull() { translate(Hp) sphere(r = 8.6); ell([1.2, 9.8, -24], [7.0, 7.0, 12]); ell(K + [0.4, 0, 0], [5.2, 5.0, 5.0]); }   // thigh
    hull() { ell(K + [0.4, 0, 0], [5.0, 4.8, 5.0]); ell([-1.6, 8.7, -72], [4.9, 4.6, 11]); translate(A) sphere(r = 2.9); }  // shin + calf
    hull() {                                                    // foot, toes turned out a little
        ell(A, [3.0, 3.2, 3.0]);
        ell([-3.5, 8.3, fz + 3.2], [3.0, 3.0, 3.2]);
        ell([17.0, 9.8, fz + 2.3], [4.5, 5.2, 2.3]);
        ell([23.5, 10.4, fz + 1.7], [3.0, 4.4, 1.7]);
        translate([-3.5, 8.3, fz]) scale([2.6, 2.6, 1]) cylinder(r = 1, h = 0.4);     // flat sole
        translate([19.0, 10.0, fz]) scale([6.5, 4.4, 1]) cylinder(r = 1, h = 0.4);
    }
    translate([7, 9.2, fz - 3]) cylinder(r = 1.5, h = 3.01, $fn = 20);   // base peg
}

module neck() hull() { ell([-0.8, 0, 50], [6.4, 6.4, 3]); translate([0, 0, 68.9]) cylinder(r = 5.8, h = 0.1, $fn = LP); }

module rail() hull() {
    for (y = [-rail_hw + 1, rail_hw - 1], z = [rail_bot + 1, rail_top - 1]) translate([lip_back + 1, y, z]) sphere(r = 1, $fn = LP);
    for (y = [-rail_hw - 1.5, rail_hw + 1.5], z = [rail_bot + 4, rail_top + 1]) translate([rail_front, y, z]) sphere(r = 1, $fn = LP);
}

module body_solid() {
    torso(); neck(); rail();
    mir() { arm(); leg(); }
    translate([0, 0, 69]) cylinder(r = 1.95, h = 4, $fn = 24);                     // head peg (Ø3.9)
    translate([0, 0, 72.6]) cylinder(r1 = 1.95, r2 = 1.6, h = 0.4, $fn = 24);
}

// T-channel + tab groove, open at the top
module channel() {
    top = rail_top + 20;
    translate([pfx - pt - c_x, -(pw / 2 + c_y), ch_bot]) cube([pt + c_x, pw + 2 * c_y, top - ch_bot]);
    translate([lip_back - 5, -mouth, ch_bot]) cube([5 + lip_t + 0.01, 2 * mouth, top - ch_bot]);
    translate([pfx - 0.1, -tab_hw, ch_bot]) cube([tab_d + 0.1, 2 * tab_hw, top - ch_bot]);
    // the plate's boss and joint-1 ball hang below the plate edge: open the mouth and a centre
    // slot out through the rail bottom so they pass; the plate edges still land on the floor
    translate([lip_back - 5, -mouth, rail_bot - 5]) cube([5 + lip_t + 0.01, 2 * mouth, ch_bot - rail_bot + 5.01]);
    translate([lip_back - 5, -tab_hw, rail_bot - 5]) cube([5 + lip_t + pt + c_x + tab_d, 2 * tab_hw, ch_bot - rail_bot + 5.01]);
    // top lead-in: chamfer the lips so the plate finds the channel
    translate([0, 0, rail_top - 1.2]) hull() {
        translate([lip_back - 0.01, -mouth, 0]) cube([0.01, 2 * mouth, 0.01]);
        translate([lip_back - 0.01, -mouth - 1.2, 1.3]) cube([lip_t + 0.02, 2 * mouth + 2.4, 0.01]);
    }
}

// level pins: holes through both lips into the rail, one pair per level
module pin_holes() for (d = LEVELS, s = [-1, 1]) {
    z = pz - ph / 2 + d - pin_hole_r - 0.05;
    translate([lip_back - 1, s * pin_y, z]) rotate([0, 90, 0]) cylinder(r = pin_hole_r, h = lip_t + pt + c_x + 1 + 2.2, $fn = 16);
}

// tick marks on the rail sides at each level; the design level (DZ = 0) gets a long one
module ticks() for (d = concat([DZ_MIN], LEVELS), s = [-1, 1]) {
    z = pz - ph / 2 + d;
    len_ = d == 0 ? 6 : 2.5;
    translate([lip_back + 0.8, s * rail_hw - 0.3, z - 0.25]) cube([len_, 0.6, 0.5]);
}

module cavity() {
    intersection() {
        torso(2.0);
        translate([-9.2, -40, -8]) cube([40, 80, 54]);
    }
    translate([0, 0, -26]) cylinder(r = 1.2, h = 20, $fn = 16);                                   // drain through the crotch
    translate([pfx, 0, 40]) rotate([0, 90, 0]) cylinder(r = 1.0, h = 8, $fn = 16);                // vent into the tab groove
}

module body() {
    difference() {
        intersection() { body_solid(); translate([-100, -100, fz - 3]) cube([200, 200, 300]); }
        channel(); pin_holes(); ticks(); cavity();
    }
}
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

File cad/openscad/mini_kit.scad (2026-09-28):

// 1:8 scale articulated resin replica kit of the Barney tail (Anycubic Photon Mono 5s)
// ----------------------------------------------------------------------------------
// One piece per vertebra: snap-fit socket cup (3 flex slits) at the proximal end, ball on a
// kinked neck (rest curve built in) at the distal end, fins + skin ring, mushroom pegs for
// orthodontic elastics ("springs") and a twine bore ("cord"). Dimensions follow the full-size
// Barney variant (suit_tail_barney.scad) scaled 1:8, with resin-safe minimums.
//
// MINI = "vertebra" (INDEX 1..N) | "hip" | "stand" | "coupon" | "assembly"
include <suit_tail_barney.scad>
PART = "none";                 // silence the full-size dispatcher
MINI = "assembly";

S = 1 / 8;
mclear   = 0.08;               // ball-socket radial clearance (resin); tune with the coupon
cup_wall = 0.9;
slit_w   = 0.45;
fin_tm   = 0.8;                // resin-safe minimum wall
bore_m   = 0.65;               // Ø1.3 mm twine bore
peg_r    = 0.45; peg_len = 1.3; peg_head = 0.75;
$fn = 40;

Lm = L * S;
function Rb(j)   = max(RB(j) * S, 2.4);
function Rsk(j)  = Rb(j) + mclear;
function rnk(j)  = max(0.42 * Rb(j), 1.0);
function x1m(j)  = 0.45 * Rb(j) + 1.4;                  // neck stays on the child axis this far from the ball
function wm(j)   = max(spring_arm(j) * S, Rsk(j) + cup_wall + 1.2);
function RFm(i)  = max(RF(i) * S, wm(i) + 0.8);
function apm(j)  = max(span_parent(j) * S, x1m(j) + 2.5);
function rsp(i)  = max(1.4, (i < N ? rnk(i + 1) : 1.2) + 0.3);
function spine_end(i) = Lm - (i < N ? x1m(i + 1) + 2.2 : 0);

module rod(a, b, r) { hull() { translate(a) sphere(r = r); translate(b) sphere(r = r); } }
module az(a) { rotate([a, 0, 0]) children(); }             // about X: 0 dorsal (+Z), 90 -> -Y, 180 ventral, 270 -> +Y

// mushroom peg pointing radially outward from `base` (in the plane of azimuth a)
module peg(pos) {
    translate(pos) {
        cylinder(r = peg_r, h = peg_len, $fn = 16);
        translate([0, 0, peg_len]) sphere(r = peg_head, $fn = 16);
    }
}

// socket cup for joint j, pivot at the origin, opening toward -X
module cup(j) {
    Rs = Rsk(j); ro = Rs + cup_wall;
    difference() {
        intersection() {
            sphere(r = ro, $fn = 48);
            translate([-0.45 * Rb(j), -ro, -ro]) cube([2 * ro, 2 * ro, 2 * ro]);
        }
        sphere(r = Rs, $fn = 48);
        // flex slits (between the band pegs)
        for (a = [60, 180, 300]) az(a) translate([-0.45 * Rb(j) - 0.1, -slit_w / 2, 0]) cube([0.75 * Rb(j), slit_w, ro + 1]);
        // twine exit toward the child
        rotate([0, 90, 0]) cylinder(r = bore_m, h = ro + 1, $fn = 16);
    }
}

// ears on the cup carrying the child-side pegs of joint j (dorsal, ventral, left, right)
module cup_ears(j) {
    for (a = [0, 90, 180, 270]) az(a) {
        translate([-1.2, -0.7, Rsk(j) + cup_wall - 0.3]) cube([1.2, 1.4, wm(j) - Rsk(j) - cup_wall + 0.3]);
        peg([-0.6, 0, wm(j) - 0.3]);                      // sunk into the tab so it fuses
    }
}

module vertebra_mini(i) {
    d = i < N ? droop(i + 1) : 0;
    E = [spine_end(i), 0, 0];
    difference() {
        union() {
            cup(i);
            cup_ears(i);
            // spine
            rod([Rsk(i) + 0.4, 0, 0], E, rsp(i));
            // fins + mid skin ring
            x0 = Rsk(i) - 0.2; x2 = spine_end(i) + (i < N ? 1.2 : -1);
            for (a = [0, 90, 180, 270]) az(a) translate([x0, -fin_tm / 2, 0]) cube([x2 - x0, fin_tm, RFm(i)]);
            translate([0.5 * (x0 + x2), 0, 0]) rotate([0, 90, 0]) difference() {
                cylinder(r = RFm(i), h = 0.8, $fn = 64);
                translate([0, 0, -1]) cylinder(r = RFm(i) - 0.8, h = 3, $fn = 64);
            }
            if (i < N) {
                // kinked neck and the ball of joint i+1 (rest bend d built in)
                K = [Lm, 0, 0] + [-x1m(i + 1) * cos(d), 0, x1m(i + 1) * sin(d)];
                rod(E, K, rnk(i + 1));
                translate([Lm, 0, 0]) rotate([0, d, 0]) {
                    rotate([0, -90, 0]) cylinder(r = rnk(i + 1), h = x1m(i + 1));
                    sphere(r = Rb(i + 1), $fn = 48);
                }
                // parent-side pegs for joint i+1: placed in the child's rest frame, braced to the fins
                for (a = [0, 90, 180, 270]) {
                    P = [Lm, 0, 0] + [[cos(d), 0, sin(d)], [0, 1, 0], [-sin(d), 0, cos(d)]] *
                        ([-apm(i + 1), -sin(a) * wm(i + 1), cos(a) * wm(i + 1)]);
                    hull() {
                        translate(P) sphere(r = 0.7, $fn = 16);
                        az(a) translate([spine_end(i) - 1.5, 0, min(RFm(i), wm(i + 1)) - 0.8]) sphere(r = 0.7, $fn = 16);
                    }
                    translate([Lm, 0, 0]) rotate([0, d, 0]) az(a) peg([-apm(i + 1), 0, wm(i + 1)]);
                }
            } else {
                // last vertebra carries the (rigid, at this scale) foam tip
                tl = (tail_length - mech_length) * S;
                translate([spine_end(i) - 1.5, 0, 0]) rotate([0, 90, 0])
                    cylinder(r1 = last_mech_diameter / 2 * S, r2 = tip_diameter / 2 * S, h = tl);
                translate([spine_end(i) - 1.5 + tl, 0, 0]) sphere(r = tip_diameter / 2 * S);
            }
        }
        // twine path
        if (i < N) {
            d2 = droop(i + 1);
            K = [Lm, 0, 0] + [-x1m(i + 1) * cos(d2), 0, x1m(i + 1) * sin(d2)];
            rod([-1, 0, 0], E, bore_m);
            rod(E, K, bore_m);
            translate([Lm, 0, 0]) rotate([0, d2, 0]) {
                rotate([0, -90, 0]) cylinder(r = bore_m, h = x1m(i + 1) + 0.1, $fn = 16);
                rotate([0, 90, 0]) cylinder(r1 = bore_m, r2 = bore_m + Rb(i + 1) * tan(40), h = Rb(i + 1) + 0.2, $fn = 24);
            }
        } else {
            rod([-1, 0, 0], [spine_end(i) + 2, 0, 0], bore_m);
            translate([spine_end(i) + 2, 0, 0]) rotate([180, 0, 0]) cylinder(r = bore_m, h = 12, $fn = 16);   // tie-off exit (ventral)
        }
    }
}

// ---- hip mount + lumbar-belt plate (1:8) ---------------------------------------------------
module root_frame_m() { translate([-root_back_offset * S, 0, root_dz * S]) rotate([0, 180 - root_pitch, 0]) rotate([180, 0, 0]) children(); }

module hip_mini() {
    pt = max(hip_plate_t * S, 1.6);
    E = [-apm(1) - 1.5, 0, 0];
    difference() {
        union() {
            translate([-harness_plate_offset * S - pt, -hip_plate_w * S / 2, plate_z * S - hip_plate_h * S / 2])
                cube([pt, hip_plate_w * S, hip_plate_h * S]);
            // boss to the ball of joint 1 (joint-1 rest bend is part of the root pitch)
            hull() {
                translate([-harness_plate_offset * S - pt, 0, root_dz * S]) rotate([0, 90, 0]) cylinder(r = 2.6, h = 0.5);
                root_frame_m() translate(E) sphere(r = 2.0);
            }
            root_frame_m() {
                rod(E, [-x1m(1), 0, 0], rnk(1));
                rotate([0, -90, 0]) cylinder(r = rnk(1), h = x1m(1));
                sphere(r = Rb(1), $fn = 48);
                for (a = [0, 90, 180, 270]) az(a) {
                    hull() { translate([-apm(1), 0, wm(1)]) sphere(r = 0.7); translate([-apm(1) - 1, 0, 1]) sphere(r = 1.0); }
                    peg([-apm(1), 0, wm(1)]);
                }
            }
            // stand tab on the plate's front (body) face
            translate([-harness_plate_offset * S - 0.01, -3, plate_z * S - 5]) cube([3, 6, 10]);
        }
        // twine: through the ball and boss, out of the top of the boss to tie off
        root_frame_m() {
            rod([Rb(1) + 1, 0, 0], E, bore_m);
            translate([Rb(1) * 0.2, 0, 0]) rotate([0, 90, 0]) cylinder(r1 = bore_m, r2 = bore_m + Rb(1) * tan(40), h = Rb(1) + 0.2, $fn = 24);
        }
        root_frame_m() translate(E) rotate([0, 0, 0]) cylinder(r = bore_m, h = 12, $fn = 16);
        // belt-strap slots (miniature, decorative)
        for (y = [-78, 78], z = [-45, 45]) translate([-harness_plate_offset * S - pt - 1, y * S - 0.4, (plate_z + z - 14) * S]) cube([pt + 2, 0.8, 28 * S]);
    }
}

// ---- display stand: floor plate + post with a slot for the hip tab ----------------------------
floor_z = -0.55 * 1727 * S;
module stand_mini() {
    reach = 900 * S;
    difference() {
        union() {
            translate([-reach - 25, -18, floor_z]) cube([reach + 35, 36, 2.5]);
            translate([-harness_plate_offset * S, -8, floor_z]) cube([8, 16, plate_z * S - floor_z + 12]);
        }
        translate([-harness_plate_offset * S - 0.5, -3.15, plate_z * S - 5.15]) cube([3.8, 6.3, 10.3]);
    }
}

// ---- snap-fit test coupon (smallest and largest joint) -----------------------------------------
module coupon() {
    for (k = [0, 1]) { j = k == 0 ? 1 : N;
        translate([k * 14, 0, 0]) { cup(j); translate([0, 12, 0]) { sphere(r = Rb(j), $fn = 48); rotate([0, -90, 0]) cylinder(r = rnk(j), h = 6); } } }
}
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

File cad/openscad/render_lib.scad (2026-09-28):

// Render library: assembly views from the exported print STLs (fast preview; also proves the
// printed parts reassemble). Include AFTER a parameter file; see render_views*.scad.
PART = "none";
VIEW = "neutral";       // neutral | turn | max | exploded | test_section | cord | pose
SHOW_ACTOR = true;
POSE_YAW = []; POSE_PITCH = []; POSE_ROLL = [];      // simulated joint angles (deg) for VIEW="pose"
PELVIS_POS = [0, 0, 0]; PELVIS_YPR = [0, 0, 0];      // pelvis pose (mm, deg) relative to standing
MANNEQUIN = [];                                      // [[a, b, r], ...] capsules in mm (posed performer)
module stl_body(i)  { rotate([0, -90, 0]) translate([0, 0, -body_len(i)]) import(str(STL, "body_", i, ".stl")); }
module stl_cap(i)   { rotate([0, -90, 0]) import(str(STL, "cap_", i, ".stl")); }
module stl_ball(i)  { rotate([-90, 0, 0]) import(str(STL, "ball_", i, "_left.stl"));
                      rotate([90, 0, 0])  import(str(STL, "ball_", i, "_right.stl")); }
module stl_hip()    { translate([-harness_plate_offset, 0, 0]) rotate([0, -90, 0]) import(str(STL, "hip_mount.stl")); }
module stl_tip()    { rotate([0, 90, 0]) import(str(STL, "tip_adapter.stl")); }

function vyaw(i) = len(POSE_YAW) > 0 ? POSE_YAW[i - 1] : VIEW == "turn" ? 0.55 * yawl(i) : VIEW == "max" ? yawl(i) : 0;
function vpitch(i) = len(POSE_PITCH) > 0 ? POSE_PITCH[i - 1] : 0;
function vroll(i) = len(POSE_ROLL) > 0 ? POSE_ROLL[i - 1] : 0;

module spring_line(i, a) {
    // joint-i springs drawn in the parent frame at pivot i; child end follows the joint yaw a
    for (r = [90, -90, 0]) color("Crimson") hull() {
        rotate([r, 0, 0]) translate([-span_parent(i), 0, spring_arm(i)]) sphere(r = coil_od(i) / 2, $fn = 12);
        rotate([0, 0, a]) rotate([r, 0, 0]) translate([-cap_ear_x, 0, spring_arm(i)]) sphere(r = coil_od(i) / 2, $fn = 12);
    }
}

module vchain(i, n_last, envelope = false, cord = false) {
    if (i <= n_last) {
        spring_line(i, vyaw(i));
        rotate([0, 0, vyaw(i)]) rotate([0, vpitch(i), 0]) rotate([vroll(i), 0, 0]) {
            color("SteelBlue") stl_body(i);
            color("LightSteelBlue") stl_cap(i);
            if (envelope) joint_motion_envelope(i, L * 0.9);
            if (cord) color("Gold") along_x(L, 2, 2);
            if (VIEW == "neutral" || VIEW == "turn" || VIEW == "pose") color("OliveDrab", 0.18)
                along_x(L, D(i) / 2, (i < N ? D(i + 1) : last_mech_diameter) / 2);
            if (i < N) { translate([L, 0, 0]) rotate([0, droop(i + 1), 0]) color("Goldenrod") stl_ball(i + 1); }
            else { translate([body_len(i), 0, 0]) color("Goldenrod") stl_tip();
                   translate([L, 0, 0]) color("SandyBrown", 0.55) along_x(tail_length - mech_length, last_mech_diameter / 2, tip_diameter / 2); }
            translate([L, 0, 0]) rotate([0, droop(i + 1), 0]) vchain(i + 1, n_last, envelope, cord);
        }
    }
}

module skin(i_last) {
    // translucent foam-skin envelope for the neutral pose
    root_frame() for (i = [1 : i_last]) translate([(i - 1) * L, 0, 0])
        color("OliveDrab", 0.18) along_x(L, D(i) / 2, (i < N ? D(i + 1) : last_mech_diameter) / 2);
}

if (VIEW == "exploded") {
    // one vertebra exploded along its axis, ball halves split sideways
    i = INDEX;
    color("LightSteelBlue") translate([-60, 0, 0]) stl_cap(i);
    color("Goldenrod") translate([-120, 0, 0]) { rotate([-90, 0, 0]) translate([0, 0, 0]) import(str(STL, "ball_", i, "_left.stl"));
                                                 translate([0, -40, 0]) rotate([90, 0, 0]) import(str(STL, "ball_", i, "_right.stl")); }
    color("SteelBlue") stl_body(i);
    color("Goldenrod") translate([L + 60, 0, 0]) { rotate([-90, 0, 0]) import(str(STL, "ball_", i + 1, "_left.stl"));
                                                    translate([0, -40, 0]) rotate([90, 0, 0]) import(str(STL, "ball_", i + 1, "_right.stl")); }
} else {
    n_last = VIEW == "test_section" ? 4 : N;
    translate(PELVIS_POS) rotate([0, 0, PELVIS_YPR[0]]) rotate([0, PELVIS_YPR[1], 0]) rotate([PELVIS_YPR[2], 0, 0]) {
        color("DimGray") stl_hip();
        root_frame() {
            color("Goldenrod") stl_ball(1);
            vchain(1, n_last, envelope = (VIEW == "max"), cord = (VIEW == "cord"));
        }
    }
    if (len(MANNEQUIN) > 0) color("DarkOliveGreen", 0.85) for (c = MANNEQUIN) hull() { translate(c[0]) sphere(r = c[2], $fn = 24); translate(c[1]) sphere(r = c[2], $fn = 24); }
    else if (SHOW_ACTOR) performer_reference();
    color("Gainsboro") translate([-1800, -900, -0.55 * 1727 - 1]) cube([2200, 1800, 1]);   // floor
}

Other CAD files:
cad/stl/barney_tpu_liners/mouth_rings/mouth_ring_J1.stl
cad/stl/barney_tpu_liners/plate_mouth_rings_print1x.stl
cad/stl/barney_tpu_liners/seat_liners/seat_liner_J2.stl
cad/stl/figurine_1to8_resin/20_figure_body.stl
cad/openscad/render_views.scad
cad/freecad/output/suit_tail_barney.FCStd
cad/freecad/output/test_section_4joint_barney.FCStd
cad/openscad/poses/1_standing.scad
cad/openscad/poses/2_bending_over.scad
cad/openscad/poses/3_turning.scad
cad/openscad/poses/4_jerk_left.scad
cad/openscad/poses/5_jump_before_landing.scad
cad/openscad/render_views_barney.scad
cad/openscad/suit_tail.scad
cad/openscad/suit_tail_barney.scad
cad/stl/barney/ball_1_left.stl
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

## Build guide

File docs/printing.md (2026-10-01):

# Printing, materials and assembly

Everything here is for the Barney tail build. The print-ready STLs are in `cad/stl/barney/` (32 parts; each cap is two halves,
already in print orientation, flat face on z = 0); sizes and masses are in `docs/tables/barney_parts.md`. The 1:8
resin kit has its own guide in `cad/stl/replica_1to8_resin/README.md`.

Barney-specific notes:
- **Hip mount:** prints plate-down and **needs no supports**.
  - **Boss:** starts on the plate's front face, so the part of it that hangs below the plate edge (a rounded lobe of
    the plate) sits on the bed.
  - **Arms:** each spring-anchor arm stands on a thin 3-line web down to the plate, flaring at 45° to the full 12 mm
    arm.
  - **Plate:** a honeycomb of hex lightening holes (22 mm across flats, a uniform 6 mm web) are cut clear of the boss, webs and
    strap slots.
  - **Cord knot:** the cord ends in a **knot chamber** bored about 39 mm up into the boss from the front (belt)
    face.
    - **Size:** Ø26 mm for the first 13 mm, then a 45° step to Ø22 mm through the flange-nut zone (3.3 mm walls),
      then a 45° roof into the cord bore.
    - **Knot:** a figure-eight or double-overhand stopper knot sits inside the boss.
    - **Loose end:** it runs down a 10 mm pointed-arch **rope tunnel** to the bottom edge of the lobe. The tunnel
      is open to the belt face, and the belt panel closes it when worn.
    - **Printing:** every roof is 45°, so it prints face-down with no supports. It replaces the old knot window.
    - **Picture:** `results/cad_renders_barney/hip_mount_knot_chamber.png`.
- **Belt attachment:** thread 25 mm hook-and-loop straps through the four corner slots and around the lumbar belt's
  back panel; the top 50 mm slot takes an optional extra webbing strap. (There used to be a bottom one too, but it
  sat under the boss where no strap could pass, so it was removed.)
- **Ball halves:** each carries its joint's rest-bend wedge (up to ±20°), so keep them in joint order.

## Printer and nozzle: Ender 3 V2 + Sprite Pro, 1.2 mm nozzle

The whole geometry is dimensioned around a 1.2 mm nozzle:

| Setting | Value | Why |
|---|---|---|
| Extrusion width | 1.3 mm | Every wall, fin and rib in the CAD is a whole number of lines (`line_w = 1.3`) |
| Layer height | 0.6 mm frames, caps and hip mount; 0.4 mm ball halves | 50 % of the nozzle; finer layers make the ball's bearing band smoother |
| Perimeters | 3 (= 3.9 mm) | Socket walls are 5 lines (6.5 mm) so the roll-key slot keeps a 2.5 mm back wall |
| Infill | 20 % gyroid; **100 % for ball halves of joints 1–3** | The root necks carry the highest bending moment (see docs/design.md) |
| Top/bottom | 3 layers | |
| Nozzle / bed | PETG 240–250 °C / 80 °C, fan 30–50 % | Big nozzles need higher flow: keep volumetric flow ≤ ~25 mm³/s on the Sprite Pro |
| Speed | 25–35 mm/s outer wall | At 1.3 × 0.6 mm this is already 20–27 mm³/s |

Minimum feature sizes used in the design:

- Two-line fins (2.7 mm) on vertebrae 4–8, three-line fins (4.0 mm) on vertebrae 1–3.
- No wall thinner than two lines.
- Holes are modelled at clearance size (M4 → 4.5 mm). With a 1.2 mm nozzle, small horizontal holes come out
  undersize and slightly oval, so **drill them to size**: 4.5 mm for M4, 3.4 mm for M3, 4.5 mm for spring holes.
- Ball-to-socket running clearance is 0.4 mm radial, plus a 0.5 mm allowance for the PTFE tape or thin felt seat
  liner. This is sized for the ±0.3 mm dimensional scatter typical of 0.6 mm layers.
- Nut pockets are M4 hex, 7.0 mm across flats + 0.4 mm. The nylock nut presses in.
- **Overhangs:** an earlier version of this guide said every overhang was ≤ 45°. A measurement of the exported
  STLs showed that was wrong:
  - **Vertebra bodies:** 3,000–4,800 mm² of near-flat ceiling each, under the socket-bowl floor between the fins
    and under the skin ring.
  - **Hip mount:** about 1,700 mm², under the boss and the arms.
  - **Ball halves and caps:** only small patches.

  The bodies and hip mount were redesigned to carry those overhangs themselves (see "Self-supporting by design"
  below). Only short bridges remain.

## Self-supporting by design (no slicer supports)

A measurement of the first exported STLs found real flat ceilings on the vertebra bodies (3,000–4,800 mm² each)
and the hip mount. Instead of break-away supports, the geometry itself now carries every overhang, with thin
structural walls that stay in the part:

- **Socket housing floor:** a solid 45° cone under the housing, running down to the spine tube.
- **Skin ring:** a single-line (1.4 mm) skirt wall stands on the bed under the ring's bottom rim.
  - At the top it flares at 45° out to the rim's full 3.9 mm width.
  - Pointed arches (vertical sides, 45° peak) open from the bed between the fins, to save plastic.
  - A 6 mm foot ties each strut's bottom out to the outer base ring.
  - Arched notches leave room at the spring anchors.
- **Hip mount:** the boss stands on the bed, the arm webs and flares described above, and plate lightening holes.
- **Fin windows:** now cut from the fins only, so they never notch the new cone.

**Every part prints from `cad/stl/barney/` with slicer supports off.**

- **Ball halves:** need no supports.
- **Short roofs Cura bridges (with bridge settings on):**
  - the 3.6 mm pockets in caps 2–3;
  - the Ø14 mm spring pocket roof and a 5 mm side slot in the tip adapter;
  - bolt-hole roofs and the 7 mm nut-pocket bridges.
- **Checker:** `cad/add_support_columns.py` reports any remaining overhang (use `--write` to emit break-away
  columns). A test asserts that the bodies and hip mount need none.

**Cost:** the new walls add about 126 g of PETG to the six bodies. The hip mount got about 15 g lighter (243 → 228 g). The as-built
physics was re-run with these masses:
- **Behaviour:** essentially unchanged. Overshoot is within 0.3°, the whip ratio moved 1.94 → 1.95, and there's
  still no floor contact.
- **Loads:** about 5 % higher. The belt peak is 14.1 N·m (was 13.3), and the lowest neck safety factor is 3.4 (J5).
- **Springs:** the spring schedule rose about 5 % to carry the weight.

## Orientation per part

| Part | Orientation (as exported) | Notes |
|---|---|---|
| `body_i` (vertebra frame) | Distal flange on the bed, socket bowl facing up | The bowl prints as an open cup; fins are vertical plates with 45° diamond windows. The bowl floor and the skin ring underside are flat ceilings: **use the supported STL** |
| `cap_i_a`, `cap_i_b` | Equator face (bolt lobes, spring ears) on the bed, as exported | Two halves split through the axis; the split faces are vertical, so splitting adds no overhang. Inner sphere becomes a 45° relief cone above 45° latitude, so there is no ceiling |
| `ball_i_left/right` | Clamshell halves, split face on the bed | Layers run **along** the neck, so neck bending loads the layers in-plane (strong). The dorsal hole captures the roll-key screw head. Align with two 1.75 mm filament dowels and glue with CA/epoxy (optional; the socket and flange bolts already trap the halves) |
| `hip_mount` | Harness-plate face on the bed, boss up | The boss overhangs the plate edge and the arms have sloped undersides: **use the supported STL** |
| `tip_adapter` | Flange on the bed | Foam spike and barbs are cones |
| `test_ballast_plate` | Flange on the bed | Only for the 4-joint test section |

All parts fit a 200 mm cube; the largest is `hip_mount` at 151 × 190 × 58 mm (`parts.json` gives every bounding box).

## Material choice

### Recommended: PETG for all structural parts, TPU only as optional bumpers

(Exceptions: TPU 95A spring straps, seat liner webs, cap-mouth bumper rings and M4 washers, printed with a 0.4 mm
nozzle. See [tpu_bands.md](tpu_bands.md).)

- **PETG** bonds well between layers with a 1.2 mm nozzle (thick, hot lines), is tough rather than brittle, and
  its glass transition (~80 °C) survives a hot costume and a car boot. A lightly-filled PETG frame is lighter than
  a solid resin part of the same shape.
- **PLA** is stiffer but brittle in impact and creeps near 50–55 °C (a sun-baked suit). Fine for a first dry-fit
  of the 4-joint section; not for performance use.
- **TPU 95A** is optional: a 1.2 mm cap-mouth pad (in place of the adhesive felt pad, `stop_pad = 0.8 mm`) or
  sleeve bumpers. The physics model already treats the stops as soft (12 ms time constant).

### Resin (Anycubic Photon Mono 5s, ABS-Like Pro 2): advice

I checked resin against the physics numbers rather than dismissing it.

1. **Build volume.** The Mono 5s's short axis is ~123 mm. Vertebra frames 1–2 are 150 and 133 mm across and do not
   fit. Resin could only ever make balls, caps and the distal frames.
2. **Mass.** Resin parts are solid unless hollowed (~1.1–1.2 g/cm³ solid, against ~0.6–1.0 g/cm³ effective for
   20 % PETG). The simulation is most sensitive to distal mass, and the distal segments are already over the
   README budget (docs/physics.md, "mass budget"), so solid resin would make that worse.
3. **Toughness.** ABS-like resins are much tougher than standard resin but still far below PETG in notched impact.
   The largest loads come from stop impacts and floor strikes. These land on the ball necks and cap lips, which is
   exactly where a brittle failure would release a joint (the cord still holds the chain together).
4. **Where resin *would* help:** sphericity and surface finish of the ball, which lowers and evens out the
   friction. The model shows that friction consistency matters more than its absolute value (the springs are
   sized from friction).

**Verdict: not recommended for structural parts.** The physics would allow resin *ball halves for joints 4–8
only*, hollowed with 2 mm walls and a drain hole in the split face, for a smoother bearing, provided they pass the
drop test in the 4-joint procedure. PETG balls wet-sanded to 400 grit, with PTFE tape in the seat, give most of
the same benefit at no risk. That is the default.

## Hardware (Barney tail, 6 joints)

| Item | Qty | Use |
|---|---|---|
| M4 × 16 socket-head cap screw + M4 nylock | 24 + 24 | Cap bolts (4 per joint) |
| M4 × 16 socket-head cap screw + M4 nylock | 24 + 24 | Ball flange → hip mount (J1) / previous body's distal flange (J2–J6), 4 each |
| M4 × 12 socket-head (roll key), all 6 joints | 6 | Head captured inside the ball; protrudes 3 mm into the socket slot |
| M3 × 8 screws | 4 | Tip adapter to body 6 |
| 25 mm hook-and-loop straps / 50 mm webbing | 4 / 1 | Hip-mount plate to the lumbar belt (corner slots / top slot) |
| Extension springs | 3 per joint (18) | Dorsal + left + right; see `docs/tables/barney_springs.md` |
| 6 mm braided polyester cord | ~1.5 m | Central cord, knotted in the knot chamber of the hip mount (loose end down the rope tunnel) |
| Compression spring Ø ≤ 13 mm, ~2 N/mm, 20 mm long | 1 | Cord preload at the tip adapter (compress ~5 mm for 10 N) |
| PTFE tape 0.25 mm or 0.5 mm self-adhesive felt | — | Seat liner (the friction level the physics was tuned for is MEDIUM ≈ felt, μ ≈ 0.25) |
| Adhesive felt/rubber 0.8 mm | — | Cap-mouth stop pad |
| 1.75 mm filament | 12 × 10 mm | Ball-half dowels (2 per ball) |

## Assembly

1. Drill all holes to size. Press M4 nylocks into the body pockets (cap lobes and distal flange).
2. Put the roll-key screw in one ball half (head in the pocket, shank out through the dorsal hole). Close the
   second half on the dowels; glue if wanted.
3. Bolt the ball's flange to the previous vertebra's distal flange (joint 1: the hip mount), bolt heads on the neck side.
4. Line the seat with PTFE tape or felt. Put the ball in the seat with the roll-key screw in the dorsal slot.
   Close the two cap halves around the neck about 5 mm back from the body (half `b`, with the dorsal ear and key
   slot, on the roll-key side). Slide the closed cap forward so the screw enters the key slot from its open end,
   then bolt it with 4 × M4 × 16 (2 per half).
   - **Why two halves:** a one-piece cap's opening is smaller than the ball and its flange, so it can never be
     fitted. The split runs through the axis 22.5° from dorsal, clear of the ears, bolt lobes and key slot by at
     least 2.4 mm.
   - **Why not straight in:** a collision check of every joint's ball, roll-key screw and cap halves confirms this
     path is clear. Pushing half `b` straight into place would hit the screw.
5. Hook the three springs of each joint: parent fin hole (or hip-mount arm) → cap ear of the child.
   Dorsal = the stiff, strongly preloaded one.
6. Thread the cord from the tip adapter through every bore and out of the hip mount's front (belt-side) face. Tie a
   figure-eight or double-overhand stopper knot, pull it up into the knot chamber, and tuck the loose end down the
   rope tunnel. At the tip,
   add washer + compression spring + washer + cord lock, and compress the spring to the preload
   (10 N ≈ 5 mm at 2 N/mm).
7. Slide on the foam skin (upholstery foam, 20 mm at the root tapering to 4 mm) and glue it to the rings and fin
   edges. Glue the 200 mm foam tip over the tip-adapter spike.

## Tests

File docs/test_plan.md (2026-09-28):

> **Barney tail:** the complete tail is only 6 joints, so it is its own prototype. Run the measurements below on the full tail (the ballast rod is not needed). The 4-joint section and predictions below are from the original 8-joint design.

# 4-joint physical test section (README section 21)

**Build:** hip mount + vertebrae 1–4 (with caps, balls 1–4 and their springs) + `test_ballast_plate` on
vertebra 4's distal flange. STLs are collected in `cad/stl/test_section/`; the assembly is in
`cad/freecad/output/test_section_4joint.step`. Articulated length is 600 mm, using the full-scale root joints.

**Ballast:** vertebrae 5–8 and the foam tip are replaced by an M8 threaded rod through the ballast plate, carrying
steel washers:
- total **625 g**, with the washer stack centred **~290 mm beyond the joint-5 ball centre**;
- this gives the same distal mass and first moment of mass, so joints 1–4 see full-tail static loads;
- the simulated response with and without ballast is in `results/figures/test_section_hip_snap.png` and
  `results/data/test_section_metrics.json`.

## Simulated predictions for the test section (compare against the filmed hip snap)

| 30° hip snap in 0.35 s | Lag | Overshoot | Swing-backs | Settling | 45° turn overshoot | Walk tip/hip ratio |
|---|---|---|---|---|---|---|
| 4 joints + 625 g ballast rod | 32.1° | 11.9° | 1 | 1.2 s | 35.5° | 1.88 |
| 4 joints, no ballast | 27.9° | 27.3° | 1 | 0.8 s | 29.6° | 1.34 |
| Full 8-joint tail, as built (for reference) | 38.6° | 10.3° | 1 | 1.9 s | 28.7° | 1.61 |

With ballast, the test section reproduces the full tail's character, so tuning the liner and springs on it
carries over.

## Measurements, and what each one calibrates in `tailsim`

| # | Test | Method | Model parameter | Pass criterion |
|---|---|---|---|---|
| 1 | Rest droop | Mount the hip plate on a rigid fixture; measure the vertebra-4 end height | Dorsal spring T0 per joint | Within ±15 mm of the model's rest pose |
| 2 | Breakaway torque per joint | Spring scale on the vertebra-4 end, pulled sideways slowly; record the force at first motion, with and without the cord | Seat μ (`mu`), `friction_radius_factor` | Within ±30 % of `μ·R·N` from the model; adjust `mu` |
| 3 | Yaw stiffness | Force vs lateral deflection at the V4 end (5 points, both directions) | Lateral spring k, preload margin | Slope within ±20 % of `stiffness_at_rest()` |
| 4 | Twist check | Twist V4 by hand ±5° about its axis and release | Twist-mode stability (cap-ear anchors) | Returns to centre; no slow corkscrew drift |
| 5 | Pluck test | Deflect V4 end 100 mm sideways, release, film at 120 fps from above | Viscous `visc` and μ | Number of visible swings and decay within ±1 swing of the simulation |
| 6 | Hip snap | Rotate the fixture 30° in ~0.35 s by hand against a stop; film from above | Whole model | Lag/overshoot trace matches `test_section` simulation shape |
| 7 | Stop impact | Drop test: release from full yaw against the stop 20 times | Stop pads, neck strength | No cracking; pads intact |
| 8 | Floor strike | Swing the V4 end into a padded floor 20 times | Neck + cap-lip strength | No cracking; cord keeps the chain intact |
| 9 | Worn-by-performer | Harness on the performer; walk, turn, crouch | Harness load path | No hot spots; tail clears legs and floor |

After tests 2–5, update the corresponding `TailParams` values and re-run `experiments/run_suite.py` before
printing vertebrae 5–8.

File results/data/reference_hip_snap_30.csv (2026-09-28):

time | pelvis_x | pelvis_y | pelvis_z | pelvis_yaw | pelvis_pitch | pelvis_roll | joint1_yaw | joint2_yaw | joint3_yaw | joint4_yaw | joint5_yaw | joint6_yaw | joint7_yaw | joint8_yaw | joint1_pitch | joint2_pitch | joint3_pitch | joint4_pitch | joint5_pitch | joint6_pitch | joint7_pitch | joint8_pitch | joint1_roll | joint2_roll | joint3_roll | joint4_roll | joint5_roll | joint6_roll | joint7_roll | joint8_roll | tip_x | tip_y | tip_z | tip_vx | tip_vy | tip_vz | tip_ax | tip_ay | tip_az | tip_heading | tip_displacement | cord_tension | floor_force | joint1_ball_force | joint2_ball_force | joint3_ball_force | joint4_ball_force | joint5_ball_force | joint6_ball_force | joint7_ball_force | joint8_ball_force | joint1_neck_moment | joint2_neck_moment | joint3_neck_moment | joint4_neck_moment | joint5_neck_moment | joint6_neck_moment | joint7_neck_moment | joint8_neck_moment
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

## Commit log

2026-09-28 estimated-2000-tokens_Add project brief, agent ground rules and gitignore
2026-09-28 estimated-90000-tokens_Add twist-stable spring geometry, parametric OpenSCAD/FreeCAD tail and CAD tests
    [suit_tail.scad]
2026-09-28 estimated-120000-tokens_Add physics study results, CAD renders, STL/STEP/FCStd exports and design docs
    [ball_1_left.stl, ball_1_right.stl, ball_2_left.stl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]
2026-09-28 estimated-45000-tokens_Add as-built and same-hardware studies, test-section predictions, strength/spring/mass tables and animations
2026-09-28 estimated-40000-tokens_Add Gojira hover-profile mechanism comparison (hinge, elastic, stop-held, spring spine), jump/bend motions and pose renders
2026-09-28 estimated-90000-tokens_Add Gojira 10-joint CAD variant: wedge-flange balls, STL/STEP/FCStd exports, as-built physics, CAD pose renders, photos and build tables
    [1_standing.scad, 2_bending_over.scad, 3_turning.scad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]
2026-09-28 estimated-3000-tokens_Refresh CAD renders and FreeCAD/STEP after final cap-ear shape; printability test covers Gojira parts
    [cap_1.stl, cap_10.stl, cap_2.stl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]
2026-09-28 estimated-15000-tokens_Add 1:8 resin display replica exports; fix tip-adapter spike and clean all STLs to single volumes
    [ball_10_left.stl, ball_10_right.stl, ball_1_left.stl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]
2026-09-28 estimated-120000-tokens_Replace variants with Barney-style 0.9 m lumbar-belt tail: CAD, STLs, FreeCAD/STEP, physics, renders, photos and 1:8 snap-fit resin kit
    [00_snap_test_coupon.stl, 01_hip_mount_plate.stl, 11_vertebra_1.stl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]
2026-09-28 estimated-60000-tokens_Reverse-sigmoid Barney tail: level start, dip, end sticks straight back; regenerated CAD, STLs, FreeCAD/STEP, 1:8 kit, physics, renders and photos
    [00_snap_test_coupon.stl, 01_hip_mount_plate.stl, 11_vertebra_1.stl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]
2026-09-28 estimated-90000-tokens_Add 1:8 low-poly protogen-head figurine (5 ft 8 in male) with T-slot back rail taking the resin tail plate at 14 pinned levels; STLs, checks, previews, docs
    [20_figure_body.stl, 21_protogen_head.stl, 22_display_base.stl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]
2026-09-29 estimated-60000-tokens_Add built-in break-away support columns to life-size STLs (cad/stl/barney_supported); correct printing guide's no-supports claim; test column clearance
    [ball_1_left.stl, ball_1_right.stl, ball_2_left.stl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]
2026-09-29 estimated-150000-tokens_Make vertebra bodies and hip mount self-supporting: 45° housing cone, single-line arched skin-ring skirt, hip arm webs/flares, boss on bed, front-face cord knot seat, hex-ligh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
    [ball_1_left.stl, ball_1_right.stl, ball_2_left.stl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]
2026-09-29 estimated-40000-tokens_Port self-supporting hip mount and vertebra frames to the FreeCAD model (convex hulls via scipy), rebuild Barney FCStd/STEP, regenerate CAD and pose renders
    [suit_tail_barney.FCStd, suit_tail_barney.step, test_section_4joint_barney.FCStd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]
2026-09-29 estimated-1000-tokens_Update generated pose files to match the re-run as-built simulation
    [1_standing.scad, 2_bending_over.scad, 3_turning.scad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]
2026-09-29 estimated-45000-tokens_Hip mount: larger 22 mm hex honeycomb (flat-to-flat, uniform 6 mm webs, 17 holes, +33% open area), 22 x 10 mm cord knot pocket with pointed 45° roof; rebuild FreeCAD/STEP, rend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
    [hip_mount.stl, suit_tail.scad, suit_tail_barney.FCStd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]
2026-09-29 estimated-30000-tokens_Hip mount: knot chamber bored ~39 mm up into the boss (26 mm, stepping to 22 mm past the flange nuts, 45° roof) plus arched rope tunnel down to the bottom edge; FreeCAD/STEP, r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
    [hip_mount.stl, suit_tail.scad, suit_tail_barney.FCStd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]
2026-09-29 estimated-20000-tokens_Bodies: 6 mm foot ties each skirt strut to the outer base ring; re-run as-built physics, tables, FreeCAD/STEP, renders
    [2_bending_over.scad, 3_turning.scad, 4_jerk_left.scad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]
2026-09-29 estimated-15000-tokens_README: linear full-size assembly order (caps go on the ball necks before closing the balls); fix printing-guide step order, Barney hardware table, roll-key sizes and PETG total
2026-09-29 estimated-60000-tokens_Fix critical assembly flaw: one-piece caps could never be fitted (mouth smaller than ball and flange); print each cap as two halves split 22.5° from dorsal, verified by per-joi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
    [cap_1.stl, cap_1_a.stl, cap_1_b.stl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]
2026-10-01 estimated-5000-tokens_Spring schedule: installed length is the true anchor-to-anchor span at rest (rest-bend wedges tilt the parent fin; dorsal J2-J6 are 75/62/33/29/34 mm, not the straight-line valu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
2026-10-01 estimated-130000-tokens_Printed TPU strap stand-ins for the 18 Barney extension springs: strap pairs (dorsal) / single near-side straps (lateral) bolted through the existing spring holes, sized from 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
    [alt_band_J2D_if_no_95a.stl, band_J1D.stl, band_J1D_tight2mm.stl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]
2026-10-01 estimated-180000-tokens_TPU 95A stand-ins on a 0.4 mm nozzle: all-95A spring straps (rate matches on 15/18 positions; J1/J4/J5 dorsal stiffer, T0 exact) with debossed joint/side label tabs, one-plate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
    [alt_band_J2D_if_no_95a.stl, band_J1D.stl, band_J1D_tight10.stl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]
2026-10-12 estimated-120000-tokens_Revision 3 assembly: one-piece balls with long-hex-key access holes (all 4 flange bolts on J1/J4, 2 on J2/J3/J5/J6 where the bent neck covers the others; those flanges bonded)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
2026-10-12 estimated-150000-tokens_Fastener tool-access test: every bolt checked at its assembly step for insertion room and >=50 mm straight hex-key room (61/61 pass); 6 cap bolts tightened with the joint bent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
